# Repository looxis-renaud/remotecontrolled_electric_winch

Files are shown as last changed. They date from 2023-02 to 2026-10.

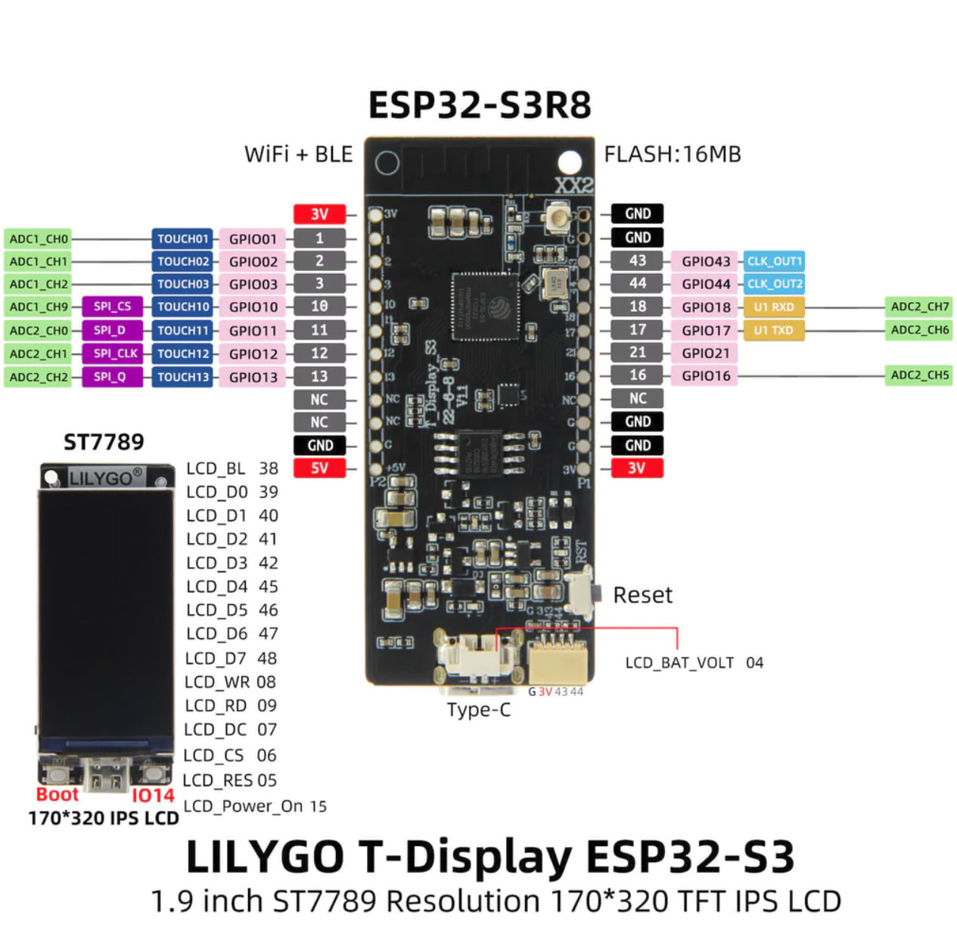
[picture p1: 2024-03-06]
doc/t-display-s3-pinout.jpg

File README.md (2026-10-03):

# Remote Controlled Electric Paraglider & Hangglider Winch

  - https://www.youtube.com/shorts/iNt1cCAZv0I (outdated video, will need to make a new one)

This is not a step by step guide of how to build your own electrical paraglider and hangglider winch, but it contains
most resources needed to build your own, including links to the most important components
- see doc/winch-schema.jpg for a simplified overview of all components needed
- doc/parts-list.md contains a list of the main parts and where to purchase them

This is not a finished project, rather a "work in progress". As of Sept. '26 I am currently improving some things, cleaning up,
changing the controller's case to a 3D-printed version, added a Daly BMS to the Battery. More on this later.

In the video above you can see the winch hanging on a steel post. Hauling it around
(getting into the trunk of my car, getting it out again, carrying) was extremely stressful,
since the winch is quite heavy, so I spent the winter of '23/'24 to move the winch onto a bike trailer.
The winch was able to rotate around it's Z-Axis, and fitted with the same arm to guide the line upwards
during the winch process. In Summer '24 this proved to not be ideal. A friend ( Bernd ) developed
a compact "Azimuth System", which is supposed to guide the line up and down and sideways during the winch-process.

During the winter 24/25 the rotary support and the arm were removed, a new frame and the azimuth system was built
and added to the system. I have done since then multiple step tows quite successfully and am really happy with the system.

As of today (July 25), I plan to keep this repo updated

# ewinch_remote_controller
 transmitter and receiver code for remote controlling a paragliding winch
 Based on LILYGO® TTGO ESP32-Paxcounter LoRa32 V2.1 1.6 Version 915MHZ LoRa ESP-32 OLED
 (http://www.lilygo.cn/prod_view.aspx?TypeId=50060&Id=1271&FId=t3:50060:3) 

Note: The 915MHz Version can transmit/receive in 868MHz and 915MHz, the desired frequency is defined in the code (transmitter.ino & receiver.ino)
  
Sketches: `transmitter/transmitter.ino` (handheld remote) and `receiver/receiver.ino` (winch, together with its helper
`LiPoCheck.cpp/.h`). Open the `.ino` in the Arduino IDE, compile and flash. The transmitter is the version flashed on my
remote (synced Sept '26: ID 3, `myMaxPull = 95`), except that the ESP-NOW monitor code is now commented out.

 receiver uses PPM (Pulse Position Modulation) for driving the winch and (optional) UART to read additional information (line length, battery %, dutycycle)
 VESC UART communication depends on https://github.com/SolidGeek/VescUart/ - Note: Line length seems to not be correctly transmitted, falls short by a factor of ~0,7
 
## To use Arduino IDE with the Lilygo TTGO ESP32 Paxcounter LoRa32
- In Arduino IDE open File > Preferences
- in additional boards manager URLS field copy: https://raw.githubusercontent.com/espressif/arduino-esp32/gh-pages/package_esp32_index.json
- click OK
- Go to Tools > Board > Boards Manager
- In Boards Manager Search for ESP32 and install **version 2.0.15** of “ESP32 by Espressif Systems“ (pick the version in the drop-down; 3.x is not tested with this code)
- Go To Tools > Board > ESP32 and select the TTGO LoRa32-OLED Board

## Install the Arduino libraries
Use the pinned library versions from [arduino-libs/](arduino-libs/README.md): copy the folders into your Arduino library folder (Windows: `Documents\Arduino\libraries\`). Don't update them casually, see the README there.
- [18650CL](https://github.com/pangodream/18650CL) 1.0.1
- [Button2](https://github.com/LennartHennigs/Button2) 2.3.2
- [VescUart](https://github.com/SolidGeek/VescUart) 1.0.1
- [OLED-SSD1306](https://github.com/ThingPulse/esp8266-oled-ssd1306) 4.5.0
- [LoRa](https://github.com/sandeepmistry/arduino-LoRa) 0.8.0

## PIN Setup Receiver:
IO 13 (PWM_PIN_OUT) // connect to PPM Port "Servo" on Vesc

IO 14 (VESC_RX)   //connect to COMM Port "TX" on Vesc

IO 2 (VESC_TX)   //connect to COMM Port "RX" on Vesc

IO 12 (Relay Signal) (for the VESC cooling fan) // connect red wire to 5V, black wire to GND and white cable (signal) to Pin 12. Wire the VESC cooling fan through the relay module. The receiver switches the fan automatically, see "Cooling fan" below. If your relay module is active-low, set `RELAY_ACTIVE_HIGH` to `false` in `receiver.ino`. Wire colours on this winch: see the table below.

### Receiver wiring harness (this winch)
Wire colours as they leave the TTGO LoRa board, recorded by Etienne on 2026-10-03. Two 6-pin plugs: the **female** plug goes only to the fan relay (doubled / free pins leave room for a later function), the **male** plug goes to the VESC. The main supply uses the small 2-pin connector that came with the board (on the transmitter the same connector goes to the 18650 cell).

| Plug | Board pin | Wire colour | Function |
|---|---|---|---|
| 6-pin **female** | IO15 | yellow | currently not used (the relay signal was wrongly on IO15 until 2026-10-02) |
| 6-pin **female** | IO12 | white | relay signal (cooling fan) |
| 6-pin **female** | GND | green & black | ground |
| 6-pin **female** | +5V | red & blue | 5 V supply |
| 6-pin **male** | IO2 | white | UART TX → VESC COMM RX (orange wire on the pre-made COMM plug) |
| 6-pin **male** | IO13 | yellow | PPM → VESC "Servo" port |
| 6-pin **male** | IO14 | blue | UART RX ← VESC COMM TX (green wire on the VESC side) |
| 6-pin **male** | + (main supply) | red | board supply from the VESC, via the small 2-pin battery connector on the TTGO board |
| 6-pin **male** | − (main supply) | black | board ground from the VESC, via the same 2-pin connector |

Colours of pre-made cables differ: go by the signal, not by the colour.

## PIN Setup Transmitter:
IO 15 (BUTTON_UP) //together with GND connect with push button for UP Command

IO 12 (BUTTON_DOWN ) //together with GND connect with a push button for STOP/BRAKE Command

A third button (IO 14) was used for the fan relay and the line cutter. It has no function any more.

## Cockpit monitor (retired)
I lost the cockpit monitor (LilyGO T-Display S3) in mid flight, and it added extra tech to take care of,
so I won't rebuild it. Its code and docs are archived in [old/](old/README.md). The matching ESP-NOW code in the
transmitter is commented out.

# VESC
VESC is the Open Source Electronic Speed Controler developed by Benjamin Vedder ( **V**edder **E**lectronic **S**peed **C**ontroller)
Topic has been moved here: [vesc/readme.md](vesc/readme.md). Hands-on guide for VESC Tool (faults, realtime data, settings, hall sensors): [vesc/vesc-tool-guide.md](vesc/vesc-tool-guide.md).

## Cooling fan
The VESC cooling fan is switched by a relay on receiver IO 12. The receiver decides by itself, there is no button for it:
- Fan **ON** as soon as a pull state (state 1 or higher) is active, including the failsafe default pull.
- Fan **OFF** 120 s after the last pull state (`FAN_RUN_ON_MS` in `receiver.ino`). The run-on lets the VESC cool down and keeps the fan from switching on and off during step tows.
- After power-up (soft brake) the fan stays off.
- After a release the remote usually stays in state 1 or 2 while AutoStop holds the drum, so the fan keeps running (the receiver does not know about the VESC AutoStop). It switches off 120 s after the remote goes to brake, or about 140 s after the remote is switched off (20 s failsafe defaultPull, then soft brake, then 120 s run-on).
- The receiver OLED shows "Fan ON", "Fan ON (off in … s)" during the run-on, or "Fan OFF".

The emergency line cutter was dropped (WINCH-05).

# Battery
16P10S Battery using 160 Lithium Ion 21700 cells with 4.000 mAh each.
 - 3,7V nominal per cell, max 4,2V, min 2,5V
 - ~60V total, max 67,2V, min 40V
 - 4Ah per cell = 40Ah total
 - 2,4 kWh

# usage:
Pull values below are for `myMaxPull = 95` in the transmitter (set it to roughly the pilot's take-off weight).
States 2-5 scale with it: prePull 18 %, takeOffPull 55 %, fullPull 80 %, strongPull 100 %.
defaultPull (7kg) and the brakes (-7kg / -20kg) are fixed values.

- A) prepare:
  1 - turn the VESC and receiver on
  2 - MAKE SURE to have the Potentiometer connected to ADC turned fully left (in my setup! need to measure whether this is open or closed :-) )
      If the Poti is rotated to the right, either partially or fully, the winch will not operate with the predefined Pull Torque!
  3 - pull the line out to the desired length (the VESC measures the line length that is being unwound, needed for the autostop to work).
      **Always pull the line out with the soft brake active (state -1, the start state), never in neutral (state 0).**

  > ⚠️ **WARNING - pull the line out with soft brake only!**
  > In neutral nothing holds the drum. When you walk faster and then stop, the drum keeps turning and unwinds
  > line right at the drum (overrun). On launch the loose turns cause a line wrap. **This has already happened
  > once:** the wrap destroyed the line and the (3D-printed) gear of the winch. The soft brake keeps the line
  > under light tension so the drum stops when you stop.
  > (The winding gears have since been replaced: first printed in plastic to check function and fit,
  > now laser-sintered steel for permanent use.)
  4 - go through your pre-flight preparations and clip in
- B) launch:
  1 - switch to defaultPull (7kg pull value) and prePull (to tighten the line (~17kg pull value) to assist you to launch the glider
  2 - go to takeOffPull (~52kg pull value) to assist you with launching the glider and gently getting into the air with a slight pull towards a safety margin of 15-30m height
  4 - click "Up" Button to increase Pull
- C) Step Towing:
  1 - switch to defaultPull (7kg pull value) before you turn away from winch to fly back to launch site
  2 - go to prePull (~17kg pull value) during turn towards next step (towards winch) to avoid line sag
  3 - after successful turn, go to fullPull again
 
- C) Release
  Go To defaultPull (7kg pull value) before you release. After releasing, rewind the line with LOW pull only:
  **maximum state 2 (prePull, ~17kg) - never higher.**
  The AutoStop feature (modified VESC Firmware is required, see vesc/vesc_ppm_auto_stop.patch) brakes the drum
  when approx. 15m of line are left - but only reliably at low rewind speed.

  > ⚠️ **WARNING - rewind with max. state 2 only!**
  > AutoStop only works reliably if the line is rewound with little pull (max. state 2 / prePull) after releasing.
  > With more pull, the brake is not strong enough to stop the drum in time: the carabiner is pulled into the
  > azimuth system and destroys it, or the line snaps. **This has already happened once** - the line broke and
  > tangled and the whole winch had to be rebuilt. (An earlier version of this README wrongly said to rewind
  > with fullPull.)

  > ⚠️ **WARNING - do NOT switch the remote off until the line is fully rewound and AutoStop has stopped the drum!**
  > The receiver does not know about the VESC AutoStop. If the remote goes off while the line is still being
  > rewound, the receiver failsafe keeps only defaultPull for 20 s and then switches to soft brake: the drum stops
  > and the rest of the line falls onto the towing track and stays there. **This has already happened once.**
  > Keep the remote on (state 1 or 2) until AutoStop has stopped the drum, and only then switch it off.
 
- D) Neutral
  You can get to neutral state only if you are in Brake Mode (-7kg), Double Press the ButtonDown to activate it.
  **Do not use neutral to pull the line out** (see the warning in A: the drum overruns and the line wraps).
  Use the soft brake instead. (An earlier version of this README recommended neutral for pulling the line out.)

- E) Rewinding the Cable
  If something does not go as expected (during one flight, I turned off the remote too soon after release: the failsafe stopped the winch, as designed, and the line fell on the ground, see the warning in C) Release):
  - use the Potentiometer, which should be on the far left position, to gently rotate it towards the right. The motor will start to rewind the line, regardless of the measured distance.

## Several pilots / several remotes
- **One pilot:** flash `transmitter/transmitter.ino` onto one remote with any ID from 1 to 15 (`myID`) and the pilot's take-off weight as `myMaxPull`. That's all you need to tow yourself.
- **Several pilots:** prepare one remote per pilot. For each remote, change `myID` (unique, 1-15) and `myMaxPull` (that pilot's take-off weight) in the code and flash it. Put a label with ID and max pull on each remote.
- **Who controls the winch:** the receiver follows only one remote at a time. The remote that is sending keeps control as long as it is switched on (it sends every 400 ms). Another remote can only take over after the active one has been **silent for 5 s** (switched off or out of range).
- **Admin remote (ID 0):** takes over immediately, at any time. When switched on, it listens for 4 s, starts in the state the winch is currently in, and from then on its buttons control the winch. Build it so it can't be confused with the others (Etienne's admin remote has a **red case**).
- ⚠️ When the admin remote is switched off again, the receiver keeps the last state; if it was a pull state, it goes to failsafe after 1.5 s (default pull, soft brake after 20 s). After 5 s **any other remote that is still switched on takes over with whatever state it is sending**. Before switching the admin remote off, make sure the other remotes are off or in a safe state (soft brake).
- All remotes and the receiver must run the same code version (same LoRa message format), see [features/INDEX.md](features/INDEX.md).

# Roadmap / ToDo
Planned changes, open bugs and ideas are tracked in [features/INDEX.md](features/INDEX.md), one file per feature.

# Notes
from Robert's "Issue Section"
- calibrate PWM Settings for pull Values: Depending on your motor (power, KV value, diameter, etc.) you need to scale the resulting kg pull on your line.
I think the best way is to adapt the "Motor Current Max" and "Motor Current Max Brake" value in the Vesc Motor Settings (General -> Current).
You could also adapt the "Pulselength Start" and "Pulselength End" in the Vesc App settings (PPM -> Mapping) to reach the same goal.
I used a suitcase scale to measure the real pull on the line.
With my QS260 hub motor I have around ~3,6A/kg pull.
- Motor amount of Poles: 32

# Big "Thank You"

A big "Thank You" goes to Robert Zach, from whom I copied this project (and forked his code).
https://github.com/robertzach/ewinch_remote_controller
Many Thanks to Bernd Otterpohl for designing the Azimuth System and making the files available
Many Thanks to Nico Stucke and Hans Werner Stucke for making the frame and the actual azimuth system.

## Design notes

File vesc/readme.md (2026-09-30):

# VESC Introduction
VESC is the Open Source Electronic Speed Controler developed by Benjamin Vedder ( **V**edder **E**lectronic **S**peed **C**ontroller).

# The controller used on this winch: Trampa VESC 75/300

The winch runs on a **Trampa VESC 75/300** (hardware revision `75_300_R3`), driving the QS Motor 12kW 260 V4 hub motor in FOC mode.
It is flashed with the patched autostop firmware [vesc_75_300_auto_stop.bin](vesc_75_300_auto_stop.bin) (see "Line auto stop in VESC" below).

Manufacturer manual (PDF): [VESC-75-300-MKIV-MANUAL.pdf](VESC-75-300-MKIV-MANUAL.pdf)

Product page: https://trampaboards.com/vesc-75v-300a-black-anodised-non-conductive-cnc-housing--the-most-powerful-vedder-electronic-speed-controller-ever-p-26284.html

## What matters for the winch

| Topic | Controller spec | What it means for this winch |
|---|---|---|
| Voltage | 12V – 67.2V (4S–16S LiPo/Li-ion), spikes must never exceed **75V** | Our 16S battery is at exactly **67.2V** when fully charged, which is the upper limit. Braking (brake states, autostop) is regenerative and feeds energy back into the battery, raising the voltage. Braking hard with a freshly, fully charged battery is therefore the most critical case for overvoltage. Never charge above 4.2V/cell. |
| Current | 300A continuous, 400A burst, **depending on mounting, ambient temperature and air circulation** | The continuous rating assumes good cooling. That is why the VESC has a cooling fan (see main README), and why the enclosure needs airflow around the heat sink. |
| Regenerative braking | Energy is recovered during braking | Brake states (-1 soft / -2 hard) and autostop brake with motor current; see voltage note above. |
| Protection | Under/over voltage, over current, over temperature (motor and ESC) | If a limit is hit, the VESC reduces or cuts motor power, including **during a tow**. Keep the battery charged and the controller cool. |
| Real-time data | Motor temperature, current, voltage | The receiver reads battery voltage, motor temperature, tachometer and duty cycle via UART and shows them on the remote. |
| Aux power outputs | 12V 1A (switchable), 5V 1A, 3.3V 0.5A; **all combined max. 1A** | Everything powered from these outputs (e.g. cooling fan, relay, potentiometer, receiver, the winch camera from WINCH-19, depending on the build) shares this 1A budget. |

## From the manual: wiring & safety notes

Winch-relevant points from the manufacturer manual ([PDF](VESC-75-300-MKIV-MANUAL.pdf)). The PDF is the authoritative source; this is only a summary.

> **Note:** The manual describes a **newer revision (MKVI)** than the controller on this winch. Connector types and positions differ: the winch's controller has **Mini-USB** instead of USB-C, and its power-switch connector sits in a different place. The general wiring and safety rules still apply, but check port positions and pinouts on the actual device, not in the manual's drawings.

**Manufacturer warning.** Trampa states the VESC "may not be used for applications requiring fulfillment of special safety standards", explicitly naming aircraft and safety-critical environments. A tow winch is exactly such an application. The winch uses the controller anyway, so the other safety layers (VESC autostop, receiver failsafe, the rewind rule in the main README) must never be weakened or skipped.

**Minimum power path (battery → VESC):**
- Safety power cut-off.
- Fuse rated for the weakest part of the electrical system.
- Anti-spark / pre-charge: anti-spark connectors (e.g. XT90S) and/or an anti-spark switch. **Never power the VESC without pre-charge**; the capacitors must charge slowly, otherwise permanent damage may result.
- A BMS is required when the motor is used for regenerative braking. On the winch this is always the case (brake states and autostop).
- All 3 battery input cables and all 3 motor phase wires must be connected and properly insulated; wire gauge must match the current.
- Keep the controller dry; the enclosure must protect it against water.

**Connectors** (as described for the MKVI: signal ports JST-PH, 2 mm pitch. On the winch's older controller USB is Mini-USB and connector positions differ):

| Port | Manual | On this winch |
|---|---|---|
| PPM | Input from an RC receiver. Never connect one receiver to several VESCs (Y-PPM); use opto decouplers. | PPM signal from the LoRa receiver (IO13). |
| COMM | UART, I²C and ADC; on the MKVI also the power-switch pin. | UART telemetry to the receiver; potentiometer on ADC2 (see "Line auto stop in VESC"). |
| Sensors | Hall, ABI or AS5047P motor position sensors (3.3 V or 5 V). | Motor sensor cable (3 hall sensors + KTY83-122 temperature sensor) connected, FOC hall mode active since 2026-09-30. Wire colours: [doc/qs-motor/README.md](../doc/qs-motor/README.md). |
| Motor A/B/C | Phase colours: A = yellow, B = blue, C = red (for correct display in VESC Tool). | QS Motor phases. |
| CAN | Only connect CAN H and CAN L; all devices on the same battery GND. | Not used. |
| USB | Configuration, firmware update, real-time data (USB-C on the MKVI). | VESC Tool via **Mini-USB**. |
| AUX | 12 V out (SIG, software-switched). | Counts towards the 1 A aux budget above. |

**LED codes** (useful for troubleshooting):

| LED | Meaning |
|-----|---|
| Blue | Powered up |
| Green, dim | Firmware running |
| Green, bright | Driving the motor |
| **Red** | **Fault.** Connect VESC Tool and read out the fault code before the next tow. |

**Power switch.** For the MKVI, the manual describes a momentary **normally closed (NC)** switch on the COMM power-switch pin, with three wiring options (illuminated NC switch, plain NC switch, or a separate soft-start switch without auto power-off). This does not apply 1:1 to the winch's older controller, whose power-switch connector is in a different place.

**On this winch:** an on/off switch on the controller's power-switch connector. **Switch open = VESC off, switch closed = VESC on.**

*Source: Trampa VESC 75/300 manual, pages 1, 3 and 4.*

## Technical specifications (manufacturer data)

**Voltage**
- 12V – 67.2V (safe for 4S to 16S LiPo/Li-ion). Voltage spikes may not exceed 75V
- 12V 1A switchable output for external electronics
- 5V 1A output for external electronics
- 3.3V 0.5A output for external electronics
- Combined 3.3V, 5V, 12V: no more than 1A

**Current**
- Continuous 300A, burst 400A (values depend on the mounting, ambient temperature and air/water circulation around the device)

**Motor control modes**
- DC, BLDC, FOC (sinusoidal). This winch uses **FOC**.
- Sensored, sensorless or hybrid operation
- Sensorless modes: HFI, VSS, 45 Deg V0V7 HFI (Silent), 45 Deg V0 HFI, Coupled V0V7 HFI (Silent), Coupled V0 HFI
- High ERPM drivable: 100–150K (motor/system dependent)

**Supported sensors**
- Hall sensors
- Encoders: ABI, AS5047, AS5X47U, SIN/COS, TS5700N8501 (incl. multiturn), MT6816, BISSC, TLE5102, custom encoder

**Communication**
- USB, SWD
- PWM in/out (this winch: PPM input from the receiver on the "Servo" port)
- UART x2 (this winch: telemetry to the receiver on the COMM port)
- SPI and I²C
- CAN, UAVCAN and custom CAN commands
- Wireless connectivity via accessory (WiFi/BLE)
- 2x programmable GPIO pins

**Other technical features**
- Current and voltage measurement on all phases (3 phase shunts), adjustable current and voltage filters (full phase filters)
- 3 individual gate drivers
- Accelerometer and gyro (9 axis, ±2/±4/±8/±16 g full scale)
- Hibernation with wake-up via power switch options (momentary NC), automatic hibernation with adjustable timer, 20µA consumption while hibernating (less than battery self-discharge)

**Software**
- VESC Tool: https://vesc-project.com/vesc_tool (desktop), mobile apps for Android/iOS
- Motor and input setup wizards
- Scripting support (QML and LISP)

**Housing**
- Precision CNC aluminium heat sink housing, black hard anodised
- Mounting holes for easy attachment
- Outer dimensions: 141 x 82 x 18 mm

*Source: Trampa product page (manufacturer data), retrieved September 2026.*

# VESC setup (VESC Tool)

The VESC is configured with **VESC Tool** (https://vesc-project.com/vesc_tool) over USB. This section explains the setup steps and the background needed to understand them.

**Hands-on guide** (connecting, read/write, backups, terminal and faults, realtime data, ERPM and hall ranges, temperature sensor, hall detection): [vesc-tool-guide.md](vesc-tool-guide.md).

> ⚠ **Firmware:** The VESC runs **FW 5.3** with the autostop patch (read out in VESC Tool on 2026-09-30, HW `75_300_R3`). Use the matching **VESC Tool 3.01**. A newer VESC Tool may offer a **firmware update: decline it.** An update would replace the patched autostop firmware ([vesc_75_300_auto_stop.bin](vesc_75_300_auto_stop.bin)) with a stock firmware without line autostop.
>
> **Backups:** Before and after every change, save the motor and app configuration as XML files in VESC Tool and commit them to this folder with a date prefix, e.g. `260929_motor_config.xml`.

## Background: BLDC vs. FOC

The QS hub motor has a rotating outer ring with permanent magnets and fixed copper coils inside. The VESC sends current through the coils. The resulting magnetic field pulls on the magnets and turns the ring. To do this right, the VESC must know at every moment **where the magnets are** (the rotor position), so it can energise the right coil at the right time. With wrong timing the motor pulls weaker, stutters or twitches backwards.

BLDC and FOC are two ways of driving the coils:

| | BLDC (block commutation) | FOC (Field Oriented Control) |
|---|---|---|
| How | Switches the coils hard on and off in 6 fixed steps per electrical revolution | Controls the current in all three coils continuously as smooth sine waves, so the field always pulls at the optimal angle |
| Picture | Pushing a swing with single hard shoves | Guiding the swing smoothly all the way |
| Result | Simple and robust, but louder, slightly pulsing torque, less efficient | Quiet, smooth, efficient, **precise torque control** |

**The winch uses FOC** (`motor_type = 2` in all configs in this folder), and that is the right choice: the pull on the line is proportional to the motor current (torque = current × motor constant). The pull states from the transmitter end up as current commands, and FOC turns them into a smooth, non-pulsing pull.

## Background: sensorless vs. hall sensors

BLDC or FOC is about *how* the coils are driven. A separate question is *how the VESC knows the rotor position*.

**Sensorless:** A turning motor induces a voltage in its coils (back-EMF). The VESC measures it and calculates the rotor position from it (the "observer"). The problem: this voltage is proportional to speed. At standstill it is zero, at very low speed it is tiny, so the VESC cannot "see" the rotor well. When starting it has to guess. Without load this usually works; **under load it can stutter, jerk or briefly turn the wrong way.** HFI (high frequency injection) is a workaround that finds the position with an audible test signal and needs careful tuning.

**Hall sensors:** Three small magnetic field sensors inside the motor report a coarse rotor position (6 sectors per electrical revolution) over the sensor cable, **also at standstill.** In FOC hall mode the VESC uses the hall signals below `foc_sl_erpm` and switches to the more precise sensorless observer above it.

What this means on the winch (rough numbers from the config: 32 magnets = 16 pole pairs, drum diameter 0.43 m):

- `foc_sl_erpm = 2000` ERPM ÷ 16 ≈ **125 rpm of the drum ≈ 2.8 m/s (≈ 10 km/h) line speed.** Below that, hall mode uses the sensors.
- That is exactly where a winch works a lot, **at standstill or slowly, under high load:** pre-tensioning with the pilot still standing, the transition from brake to pull, braking to standstill (autostop, end of rewind), and the start of the rewind.
- With hall sensors these phases are smooth and predictable. Sensorless they can be jerky, depending on motor and tuning.

Things to know:

- **The 6-wire sensor cable also carries the motor temperature sensor** (5 V, GND, H1, H2, H3, TEMP). The motor has a **KTY83-122** sensor, so `m_motor_temp_sens_type` must be **KTY83/122** (Motor Settings → General → Advanced → Motor Temperature Sensor Type). With this setting an unplugged cable reads as extremely hot: the VESC raises `FAULT_CODE_OVER_TEMP_MOTOR` and gives no current. **The sensor cable must always be connected.**
- ⚠ **Wrong sensor type = no current.** Until 2026-09-30 the type was set to NTC 10k. The KTY83's ~1 kΩ then reads as ~100 °C, above the 75/85 °C motor limits: red LED, `FAULT_CODE_OVER_TEMP_MOTOR`, the motor doesn't turn (not even with the potentiometer). That was the "VESC error with the sensor cable connected" from WINCH-16.
- **Downside of hall mode:** the VESC depends on the sensor cable. A loose plug, broken wire or faulty sensor gives wrong positions: jerks, weak pull or fault codes. Cable and connectors must be reliable. Sensorless mode has no such dependency.
- **Plugging in the cable alone changes nothing.** The VESC only uses the sensors when the sensor mode is set to *Hall* **and** the hall table has been measured (see below).

**Current state (2026-09-30): the winch runs in FOC hall mode** (`foc_sensor_mode = 2`, backup [260930_motor_config.xml](260930_motor_config.xml)). Hall table measured: `255, 65, 118, 103, 199, 34, 173, 255`. Until then it ran sensorless (June 2024 config, now in [old/vesc-configs/](../old/vesc-configs/)). Check in VESC Tool: **Motor Settings → FOC → General → Sensor Mode.**

Note: **Motor Settings → General → "Sensor Port Mode: Hall Sensors"** only says what kind of sensor could be connected to the port (hall, ABI encoder, AS5047). It does not switch hall mode on; that is the FOC Sensor Mode.

## Hall sensors: how they were set up (and how to redo it)

> ⚠ **Safety-relevant.** Hall mode changes how the motor starts and brakes. Bench test first, then field test. Tracked in [WINCH-17](../features/WINCH-17-hall-sensors-foc.md).

Chosen because the winch spends its most critical moments (start, pre-pull, braking, autostop) at low speed under load, and because the sensor cable also provides the motor temperature protection.

**Prerequisites**
1. Sensor cable checked wire by wire (5 V, GND, H1, H2, H3, TEMP). Test procedure for the temperature sensor and the three hall sensors (German): [doc/qs-motor/sensors-troubleshooting.md](../doc/qs-motor/sensors-troubleshooting.md). Wire colours: [doc/qs-motor/README.md](../doc/qs-motor/README.md) (plug colours differ from motor wire colours). Status 2026-09-30: hall sensors of sensor set 1 intact, temperature sensor 0.97 kΩ at ~25 °C (KTY83-122).
2. Motor temperature sensor type set to **KTY83/122** (see above), otherwise `FAULT_CODE_OVER_TEMP_MOTOR`.

**Procedure** (done this way on 2026-09-30; **not** with the Setup Motor FOC wizard, which would also reset current limits, battery and temperature settings)
1. Save the current motor and app configuration as XML (backup).
2. Potentiometer at the "off" end. Secure the winch. **Unhook the line or make sure there is no load on it, and keep everyone away from the drum: the motor turns by itself during detection.**
3. Motor Settings → FOC → **Hall Sensors** tab: run only the hall detection (default detection current; increase in small steps if the motor doesn't turn).
4. Check the hall table: entries 1–6 must have values, only entries 0 and 7 are 255. If more entries are 255, a sensor or wire is faulty. Do not use hall mode then.
5. Apply the table, set FOC → General → **Sensor Mode = Hall** (Sensorless ERPM stays 2000), **write** the motor configuration.
6. Short test with the potentiometer (little travel): smooth start from standstill and smooth braking from slow speed. Then `faults` in the VESC Tool terminal.
7. Read the configuration back, save it as XML and commit it to this folder.

**Bench checks** (workshop, no pilot)
- Smooth start from standstill in the pull states, also against load (line held / tied back), no jerks or backwards twitch.
- Brake to standstill (soft brake, hard brake) without jerks.
- Motor temperature on the remote is plausible (about ambient temperature when cold).
- Line length counts up and down ([WINCH-16](../features/WINCH-16-uart-telemetry-zero.md)).
- Unplug the sensor cable deliberately once on the bench (low pull state only) to see how the VESC reacts, so the failure mode is known. Expected with the KTY83/122 setting: `FAULT_CODE_OVER_TEMP_MOTOR` (open temperature input reads as very hot), no current.

## Setup wizards

VESC Tool has two wizards on the welcome page: **Setup Motor FOC** and **Setup Input**.

### Setup Motor FOC

The wizard asks roughly for:
- the motor class (e.g. large hub motor),
- the battery (type, number of cells: 16, capacity, current limits),
- drive setup (wheel/drum diameter, motor poles: 32, gear ratio 1),

and then **measures the motor**. The motor makes noises and **turns during the measurement** (no line load, nobody at the drum). Afterwards it lets you choose the motor direction.

What it measures and calculates (values from [260930_motor_config.xml](260930_motor_config.xml); R, L and λ were measured in 2024 and are unchanged):

| Value | Config name | Value in backup | What it means in simple words |
|---|---|---|---|
| Resistance R | `foc_motor_r` | 4.34 mΩ | Electrical resistance of the copper windings. Determines the heat losses (heat = I² × R: at 200 A about 170 W in the windings) and is needed for current control. |
| Inductance L | `foc_motor_l` | 17.8 µH | How "sluggish" the windings are against changes in current. Determines how fast the VESC can change the current. |
| Flux linkage λ | `foc_motor_flux_linkage` | 26.1 mWb | Strength of the magnets as seen by the coils. The key motor constant: it links **current to torque** and **speed to voltage**. |
| Current controller gains | `foc_current_kp`, `foc_current_ki` | 0.0178 / 4.34 | Settings of the VESC's internal current regulator. Not measured but **calculated from L and R** (here L × 1000 and R × 1000). |
| Observer gain | `foc_observer_gain` | 1.47 × 10⁶ | Tuning of the sensorless position estimator (used above `foc_sl_erpm`), **calculated from λ**. |
| Hall table | `foc_hall_table__0…7` | 255, 65, 118, 103, 199, 34, 173, 255 | Which rotor angle each of the 6 hall sensor combinations stands for. Measured by the hall detection on 2026-09-30. |

Rough cross-check with λ (theoretical, ignoring friction and losses): torque per amp ≈ 1.5 × 16 pole pairs × 0.0261 ≈ 0.63 Nm/A. At a drum radius of 0.215 m that is ≈ 2.9 N per amp, i.e. **≈ 3.4 A per kg of line pull.** This fits the ≈ 3.6 A/kg estimate used for the pull states (see [WINCH-14](../features/WINCH-14-pull-value-calibration.md)). The effective drum radius grows as line is wound on, so the real value varies.

After the wizard, **compare the motor settings with the last backup.** The wizard sets current limits and other values based on the chosen motor class and battery, and these can differ from the values the winch was set up with (table below).

### Setup Input

Configures how the VESC reads the PPM signal from the LoRa receiver. The receiver outputs pulses between 950 µs (hard brake side) and 2000 µs (full pull side). In VESC Tool these are the pulse start / center / end values:

| Config | Pulse start | Center | End |
|---|---|---|---|
| [260930_app_config.xml](260930_app_config.xml) (this winch, unchanged since June 2024) | 0.933 ms | 1.458 ms | 1.984 ms |
| [old/vesc-configs/vesc_app_config.xml](../old/vesc-configs/vesc_app_config.xml) (Robert, for comparison) | 1.1 ms | 1.459 ms | 1.768 ms |

> ⚠ **Do not re-run the input wizard casually.** The pulse range defines how many amps each pull state means, i.e. the actual pull in kg. Changing it is safety-relevant, needs Etienne's decision and a bench test, and should go together with the pull calibration ([WINCH-14](../features/WINCH-14-pull-value-calibration.md)).

## Motor Settings

Motor settings are specific to the motor. **Every time a different motor is connected, the motor must be set up again** (Setup Motor FOC), otherwise the VESC and/or the motor can be damaged. Changes only take effect after the motor configuration has been **written** to the VESC.

Settings worth knowing (values from [260930_motor_config.xml](260930_motor_config.xml), read from the VESC on 2026-09-30):

| Setting | Config name | Value in backup | Note |
|---|---|---|---|
| Motor current max / min | `l_current_max` / `l_current_min` | 250 A / −250 A | Upper limit for pull and brake torque. |
| Battery current max / min | `l_in_current_max` / `l_in_current_min` | 290 A / −290 A | Max. current drawn from / fed back into the battery. Must fit the BMS. |
| Absolute max current | `l_abs_current_max` | 290 A | Hard cut-off: above this the VESC faults. |
| Battery cutoff start / end | `l_battery_cut_start` / `l_battery_cut_end` | 54.4 V / 48 V (3.4 / 3.0 V per cell) | Below "start" the VESC reduces the current, at "end" it stops. The battery voltage sags under load, so with a partly discharged battery the **pull can be reduced during a tow**. |
| Max input voltage | `l_max_vin` | 72 V | Over-voltage fault. Full battery = 67.2 V; regenerative braking raises it. ⚠ Triggered on 2026-09-30 when braking from full speed, see [WINCH-22](../features/WINCH-22-overvoltage-regen-braking.md). |
| Motor temp start / end | `l_temp_motor_start` / `l_temp_motor_end` | 75 °C / 85 °C | Current is reduced between these. **Only works with the temperature sensor connected and the right sensor type.** |
| FET temp start / end | `l_temp_fet_start` / `l_temp_fet_end` | 85 °C / 100 °C | Controller temperature; see cooling fan. |
| Motor type | `motor_type` | 2 = FOC | |
| Sensor mode | `foc_sensor_mode` | 2 = Hall | Since 2026-09-30 (was 0 = sensorless). |
| Sensorless switch-over speed | `foc_sl_erpm` | 2000 ERPM | Below this, hall mode uses the sensors; above it the sensorless observer. |
| Hall interpolation | `foc_hall_interp_erpm` | 500 ERPM | Above this, the VESC interpolates between hall sectors. |
| Motor temp sensor type | `m_motor_temp_sens_type` | 2 = KTY83/122 | Matches the motor (KTY83-122). Was 0 = NTC 10k until 2026-09-30, which caused `FAULT_CODE_OVER_TEMP_MOTOR`. |
| Auxiliary output mode | `m_out_aux_mode` | 11 = "Temp motor or mosfet > 50 C" | AUX output switches on above 50 °C. What is connected to which 12 V output: see [WINCH-07](../features/WINCH-07-automatic-cooling-fan.md). |
| Motor poles | `si_motor_poles` | 32 | 16 pole pairs. |
| Wheel (drum) diameter | `si_wheel_diameter` | 0.43 m | Used for speed/distance in VESC Tool. |
| Battery cells / capacity | `si_battery_cells` / `si_battery_ah` | 16 / 40 Ah | 16S10P × 4 Ah. |

## App Settings

App settings define which input the VESC listens to. Changes only take effect after the app configuration has been **written** to the VESC.

| Setting | Config name | Value in backup | Note |
|---|---|---|---|
| App to use | `app_to_use` | 4 = PPM and UART | PPM = pull command from the receiver, UART = telemetry to the receiver. |
| UART baud rate | `app_uart_baudrate` | 115200 | Must match `receiver.ino`. |
| PPM control type | `app_ppm_conf.ctrl_type` | 3 | "Current, no reverse, with brake" (FW 5.x numbering; confirm in VESC Tool). |
| PPM ramp up / down | `app_ppm_conf.ramp_time_pos` / `_neg` | 1 s / 0.5 s | VESC-side smoothing, on top of the receiver's own smoothing. |
| Timeout | `timeout_msec` / `timeout_brake_current` | 1000 ms / 10 A | If the PPM signal is missing for 1 s, the VESC brakes with 10 A. |

The potentiometer on ADC2 is handled by the autostop firmware patch, not by a normal app (see "Line auto stop in VESC" below).

**Toolbar:** On the right-hand side of VESC Tool there are buttons for motor (**M**) and app (**A**) configuration: *read* the configuration from the VESC, *read default* configuration, and *write* the configuration to the VESC. Always read first, change, then write. Go by the tooltips: in VESC Tool 3.01 **write** is the icon with the arrow pointing **down**.

## Config backups in this repo

| File | Origin | Content |
|---|---|---|
| [260930_motor_config.xml](260930_motor_config.xml) | Etienne, 2026-09-30 | **Current** motor config of this winch: FOC hall mode, KTY83/122 temperature sensor |
| [260930_app_config.xml](260930_app_config.xml) | Etienne, 2026-09-30 | **Current** app config of this winch (PPM + UART; unchanged since June 2024) |

Older backups (June 2024 sensorless config, Robert Zach's 2022 configs) are archived in [old/vesc-configs/](../old/vesc-configs/). Keep only the current backups here; move superseded ones to `old/vesc-configs/`.

**PLEASE NOTE:** Don't just load a motor config and write it to your VESC. Use it as an example only. Always run the **Setup Motor FOC** wizard so the VESC measures the real motor (resistance, inductance, flux linkage, hall sensors).

## Line auto stop in VESC
Line auto stop can be implemented within VESC with vesc_ppm_auto_stop.patch

For this to work properly, either connect a Potentiometer to ADC2 and GND to manually control the winch. E.g. To wind up the last meters of the line when finishing. Or to manually set a tension when used as a rewind winch. Note that the potentiometer only reduces tension/speed of the motor when it is running one of the pull programs as controlled via the transmitter!

> ⚠ **IMPORTANT: If you do not install a potentiometer, connect ADC2 to GND.** An open (floating) ADC2 input can read above 0.5 V. The VESC then switches to manual mode and ignores the remote: **the winch starts to pull on its own.** The same applies to a broken wire at the potentiometer (see failure modes below).

### Potentiometer: wiring

The potentiometer sits on the **COMM** port of the VESC (JST-PH connector). It divides the VESC's supply voltage and feeds the result to ADC2. The firmware patch compares the ADC2 voltage against the 3.3 V reference: **below 0.5 V = normal PPM operation (remote in control), above 0.5 V = manual mode** (current proportional to the potentiometer position, PPM input ignored).

Wiring on this winch (Etienne, 2026-09-30), potentiometer **viewed from below**:

| Potentiometer pin | VESC COMM signal | Wire colour (JST cable on this winch) |
|---|---|---|
| left | GND | yellow |
| middle (wiper) | ADC2 | orange |
| right | VCC | red |

- The wire colours are those of the JST cables used on this winch. Pre-made JST cables come in different colours: go by the signal on the COMM port, not by colour.
- **VCC must be 3.3 V, not 5 V.** The ADC measures up to 3.3 V. Check the voltage on the VCC wire with a multimeter before connecting the potentiometer. *To be completed:* confirmed voltage and pin position on the COMM port of this controller (the Trampa manual shows a newer revision).
- **Direction:** swapping the two outer pins reverses the direction. The "off" end is the end where ADC2 reads **0 V**. According to Etienne's notes that is **fully left (counter-clockwise)**. *To be verified* (WINCH-08).

**Check after wiring (winch secured, line without load):**

1. Turn the potentiometer to the "off" end. VESC Tool → Realtime Data (or multimeter between ADC2 and GND): ADC2 must read about **0 V** (well below 0.5 V).
2. Turn it slowly to the other end: the voltage must rise smoothly up to about 3.3 V. Above 0.5 V the motor starts to pull in manual mode.
3. Back to the "off" end: the winch must follow the remote again.

### Potentiometer: which part

| Property | Recommendation | Why |
|---|---|-----|
| Resistance | **10 kΩ** (5–10 kΩ is fine) | Only ~0.3 mA from the 3.3 V supply (the aux outputs share a 1 A budget). Much higher values make the ADC reading noisy. |
| Taper | **linear** (marked "B", e.g. "B10K") | Pull increases evenly with the rotation angle. A logarithmic ("A") taper makes the range near the off end very insensitive and then very steep. |
| Type | single-turn rotary potentiometer, 3 pins, panel mount (thread + nut), 6 mm shaft | Can be mounted securely in the enclosure wall. |
| Robustness | sealed / dust- and splash-proof if possible, solid metal housing | The winch is used outdoors. A dirty track can make the wiper jump. |
| Knob | knob with a clear pointer, "OFF" end marked on the enclosure | The "off" position must be recognisable at a glance before every tow (pre-flight check). |

### Potentiometer: failure modes

| Fault | ADC2 reads | Effect |
|---|---|---|
| ADC2 not connected / wiper wire broken | undefined (floating) | may switch to manual mode at random: **winch pulls on its own** |
| GND wire to the potentiometer broken | ~3.3 V | **full manual current**, remote ignored |
| VCC wire broken | ~0 V | manual mode no longer possible, remote works normally |
| Potentiometer not at the "off" end | > 0.5 V | manual mode, remote ignored |

Connectors and wires to the potentiometer therefore need strain relief and must be checked regularly.

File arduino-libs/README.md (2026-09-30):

# Arduino libraries (pinned versions)

Copies of the exact library versions used to build `transmitter/` and `receiver/`. They are kept in the repo so the winch firmware can always be rebuilt with the same code, even if a library changes or disappears upstream. See [WINCH-20](../features/WINCH-20-pin-toolchain-libraries.md).

**Do not update these libraries casually.** Update one library at a time, as its own feature, with a bench test (for example, a new Button2 version could change click, double-click or long-press timing, which drives the pull state machine).

## Versions

| Library | Version | Used by | Source | License |
|---|---|---|---|---|
| [Button2](Button2/) | 2.3.2 | transmitter | https://github.com/LennartHennigs/Button2 | MIT |
| [LoRa](LoRa/) | 0.8.0 | transmitter, receiver | https://github.com/sandeepmistry/arduino-LoRa | MIT |
| [VescUart](VescUart/) | 1.0.1 | receiver | https://github.com/SolidGeek/VescUart | GPL-3.0 |
| [ESP8266 and ESP32 OLED driver for SSD1306 displays](ESP8266_and_ESP32_OLED_driver_for_SSD1306_displays/) | 4.5.0 | transmitter, receiver | https://github.com/ThingPulse/esp8266-oled-ssd1306 | MIT |
| [Pangodream_18650_CL](Pangodream_18650_CL/) | 1.0.1 | transmitter, receiver | https://github.com/pangodream/18650CL | MIT |

Each folder is an unmodified copy of the installed library, including its license file. Taken from Etienne's Arduino library folder (installed February to April 2024) on 2026-09-30.

The rest of the toolchain can't be stored here and is pinned by version:

| Part | Version |
|---|---|
| Arduino IDE | 2.3.2 (the old IDE 1.8.x was removed on 2026-09-30; don't use it) |
| Board package "esp32 by Espressif Systems" | **2.0.15** (install exactly this version in the Boards Manager; 3.x has breaking changes) |
| Board | TTGO LoRa32-OLED (`esp32:esp32:ttgo-lora32`) |

## Status

- 2026-09-30: both sketches (state of WINCH-05/06/07) **compile** against exactly these copies (arduino-cli 0.35.3 from Arduino IDE 2.3.2, esp32 core 2.0.15).
- Bench and field tests with firmware built from these versions: *to be completed* after the WINCH-05/06/07 flash. The firmware on the winch before that was possibly built on another machine with unknown library versions (see WINCH-02).

## How to use them

**Arduino IDE:** copy the five library folders from `arduino-libs/` into your Arduino library folder (Windows: `Documents\Arduino\libraries\`), replacing other versions of the same libraries. Then open the sketch, select the board and compile as usual. In the IDE, *Tools → Manage Libraries* should show the versions from the table above.

**arduino-cli** (used by Claude for compile checks, no need to copy anything):

```
arduino-cli compile --fqbn esp32:esp32:ttgo-lora32 --libraries arduino-libs transmitter
arduino-cli compile --fqbn esp32:esp32:ttgo-lora32 --libraries arduino-libs receiver
```

ESP32Servo is no longer needed (line cutter removed in WINCH-05).

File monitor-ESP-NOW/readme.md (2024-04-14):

## Nearby Monitor with ESP-NOW Communication Protocol ##
 Using a Lilygo ESP32 T-Display S3 board ( https://www.lilygo.cc/products/t-display-s3 ) 
 to communicate with the Lilygo ESP32 LoRa board over ESP-NOW Protocol to
 - display winch-data and current Pull Value in Pilot's sight (on cockpit)
 - use buttons to control Fan, Warning light and Emergency Line Cutter via the transmitter
 - use a rotary encoder to be able to change the maxPull Value on the transmitter

## based on ##
 - https://github.com/VolosR/t-displayESPNOW/tree/main/Examples
 - https://www.youtube.com/watch?v=wKs2BjljM3E
 - https://randomnerdtutorials.com/esp-now-esp32-arduino-ide/
 - https://www.youtube.com/watch?v=3TswcJifxxI
 - https://github.com/VolosR/PbarrTut

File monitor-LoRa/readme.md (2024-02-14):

## Additional Lilygo TTGO ESP32 Paxcounter LoRa32 as a Monitor
 The "monitor" (monitor.ino) is basically an additional Lilygo LoRa ESP 32 that just listens
 to LoRa communication between transmitter and receiver and displays
 data on the oled display. I am "playing around" to add an external round oled or squared TFT Display
 for displaying the data nicely on a bigger screen (bigger than the original oled of the ESP32 Lora board)

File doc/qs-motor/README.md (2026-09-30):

# QS Motor 12kW 260 V4 (hub motor)

The winch drum is driven directly by a QS Motor 12kW 260 V4 hub motor. The motor housing (outer rotor) turns with the drum; the axle is fixed. The motor is driven by the Trampa VESC 75/300 in FOC mode, see [vesc/readme.md](../../vesc/readme.md).

This page collects what is known about the motor. Values marked *to be completed* are still missing. Please fill them in when known and name the source.

## Files in this folder

| File | Content |
|---|---|
| [QSMOTOR-Motor-Manual-V1.57.pdf](QSMOTOR-Motor-Manual-V1.57.pdf) | QS general motor manual: wire colours, pole pairs, hall and temperature sensor checks, temperature limits, waterproofing, mounting, hall replacement |
| [QSMOTOR-Connection-Manual-Kelly.pdf](QSMOTOR-Connection-Manual-Kelly.pdf) | QS connection manual for car hub motors with Kelly controllers: phase and hall wiring, spare hall set |
| [sensors-troubleshooting.md](sensors-troubleshooting.md) | Test procedure for the temperature sensor and the three hall sensors (German) |

## Identification

- **Model:** QS Motor 12kW 260 V4 hub motor, ordered as version "72V 100kph" ([AliExpress listing](https://www.aliexpress.com/item/4001237537247.html), see [parts list](../parts-list.md)).
- According to the QS manual, V3/V4 motors are marked "WP" on the motor.
- Serial number, purchase date, exact order specification: *to be completed*.

## Known data

| Item | Value | Source |
|---|---|---|
| Rated power | 12 kW | Product name |
| Pole pairs | **16** (32 magnets) | QS manual p. 3 (V3/V4 motors), VESC configs `si_motor_poles = 32` |
| Phase angle | 120° | QS manual p. 3 |
| Phase wires | yellow = U/A, green = V/B, blue = W/C | QS manual p. 1, Kelly manual |
| Hall sensors | 3 hall sensors, 5 V supply. **Two sensor sets** (each 3 halls + temperature sensor), one of them a spare | QS manual p. 1, Kelly manual |
| Sensor set 1 | Fitted with our own plug, in use. All 3 hall sensors measured intact | Etienne, 2026-09-30 |
| Sensor set 2 | Original QS plug (no matching counterpart), never connected, unchecked | Etienne, 2026-09-30 |
| Temperature sensor | **KTY83-122.** Measured 0.97 kΩ at ~25 °C (KTY83-122 nominal 1.0 kΩ; a PT1000 would be ~1.1 kΩ, a 10k NTC ~10 kΩ). VESC set to KTY83/122 shows plausible temperatures. Heating test (resistance must rise ~0.8 %/°C) *to be completed* | QS manual p. 3, Etienne's measurement and VESC Tool session 2026-09-30 |
| Waterproofing | IP65 (hub motors) | QS manual p. 5 |
| QS temperature limits (V2/V3/V4) | 130 °C inside the motor (for 30 s) → limit current to 50 %; 145 °C → shut down, resume at 110 °C | QS manual p. 11 |
| Phase resistance R | ≈ 4.3–5.8 mΩ | VESC motor detection: this winch 4.34 mΩ ([260930_motor_config.xml](../../vesc/260930_motor_config.xml), measured 2024), Robert's 260 V4 5.8 mΩ ([old/vesc-configs/](../../old/vesc-configs/)) |
| Inductance L | ≈ 16–18 µH (Ld–Lq ≈ 4.7 µH) | same configs |
| Flux linkage λ | ≈ 25.6–26.1 mWb | same configs |
| Torque constant Kt | ≈ 0.63 Nm/A (derived: 1.5 × 16 pole pairs × λ). With the 0.43 m drum that is ≈ 3.4 A motor current per kg of line pull, consistent with the ~3.6 A/kg used for `myMaxPull` | Calculated estimate, not measured |
| KV (rpm/V) | *to be completed* | QS spec sheet or VESC Tool |
| Rated / max phase current, rated torque | *to be completed* | QS spec sheet |
| Rated voltage range, max rpm | *to be completed* (ordered as the 72 V version) | QS spec sheet |
| Weight | *to be completed* | |

## Sensor cable wiring (sensor set 1)

Confirmed by Etienne, 2026-09-30.

> ⚠ **The plug colours do not match the motor wire colours.** Red on the plug is a hall signal, green on the plug is +5 V. Always go by this table, not by colour conventions.

| Motor wire colour | Plug wire colour | Function |
|---|---|---|
| yellow | yellow | Hall A |
| green | white | Hall B |
| blue | red | Hall C |
| black | black | GND (halls and temperature sensor) |
| red | green | +5 V (hall supply) |
| silver (QS manual: "transparent") | blue | Temperature sensor (measured against GND) |

- Hall A/B/C follow the phase wire colours (yellow = A, green = B, blue = C). Connecting Hall A/B/C to H1/H2/H3 of the VESC is the natural choice. The assignment is not critical, because the VESC hall detection works out the order itself.
- Pin positions in the VESC sensor port and which plug colour goes to which VESC pin: *to be completed*. The Trampa manual in `vesc/` shows a newer controller revision, so check on the actual device.
- The QS manual warns that the hall sensors can be destroyed by static discharge above 5 V: don't touch the contacts without grounding yourself.

## VESC settings for this motor

The VESC configuration is documented in [vesc/readme.md](../../vesc/readme.md). That file is the authority. Motor-related values in the current config [vesc/260930_motor_config.xml](../../vesc/260930_motor_config.xml):

| Setting | Value | Note |
|---|---|---|
| `motor_type` | 2 (FOC) | |
| `l_current_max` / `l_current_min` | 250 A / −250 A | Unchanged since 2024 |
| `l_temp_motor_start` / `l_temp_motor_end` | 75 °C / 85 °C | Much more conservative than the QS limits above. Only works with the sensor cable connected |
| `foc_sensor_mode` | 2 (Hall) since 2026-09-30 | Hall table `255, 65, 118, 103, 199, 34, 173, 255`. See [WINCH-17](../../features/WINCH-17-hall-sensors-foc.md) |
| `m_motor_temp_sens_type` | 2 (KTY83/122) since 2026-09-30 | Was 0 (NTC 10k) → permanent over-temperature fault. The sensor cable must stay connected |
| `si_motor_poles` | 32 | = 16 pole pairs |
| `si_wheel_diameter` | 0.43 m (Etienne 2024) | Drum diameter, used for the line length |

## Mounting and maintenance notes (QS manual)

- Keep the phase wire outlet pointing **down** so water and dirt don't collect at the axle (p. 6–8).
- Don't seal the wire outlet with glue: the motor "breathes" through it when it heats up and cools down (p. 8).
- Don't carry the motor by the phase wires; it affects waterproofing (p. 5).
- Oil seal: check regularly; QS suggests replacing it after 18–24 months of use (p. 11). Status on this winch: *to be completed*.

## To be completed

- [ ] KV, rated/max phase current, rated torque, voltage range, max rpm, weight (QS spec sheet)
- [ ] Serial number, purchase date, exact order specification
- [ ] Heating test to confirm the KTY83-122 temperature sensor ([WINCH-17](../../features/WINCH-17-hall-sensors-foc.md))
- [ ] Condition of the spare sensor set 2 (original QS plug, unchecked)
- [ ] Pinout of the VESC sensor port vs. plug colours
- [ ] Oil seal status

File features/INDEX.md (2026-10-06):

# Feature Index

> Central roadmap for all hardware, firmware and documentation changes on the winch.
> One file per feature: `WINCH-NN-<slug>.md` (template: [TEMPLATE.md](TEMPLATE.md)).

## Status Legend
- **Idea**: noted, not yet specified
- **Planned**: scope, changes and test plan written
- **In Progress**: being built / coded / written
- **Bench Test**: built, being tested in the workshop (winch on the stand, no pilot)
- **Field Test**: being tested in real towing operation
- **Done**: tested and in use
- **Dropped**: decided against; code/docs archived where applicable

**Safety-relevant** = touches pull/brake behaviour, failsafe, autostop, the LoRa protocol or anything a pilot relies on. These always need Etienne's explicit confirmation and a bench test before a field test.

## Suggested order
**WINCH-01** → 02 → 03 → 04 → 16 → 08 → 05 + 06 + 07 (one flash, struct change) → 09 → rest

## Features

| ID | Feature | Type | Status | Priority | Safety | Depends | Spec |
|----|---|---|---|---|---|---|---|
| WINCH-01 | ⚠ Fix dangerous README rewind instruction (max. state 2) | Doc | Done | P0 | Yes | – | [WINCH-01](WINCH-01-fix-readme-rewind-instruction.md) |
| WINCH-02 | Sync repo with latest local code (other machine) | FW | Done | P0 | Yes | – | [WINCH-02](WINCH-02-sync-latest-local-code.md) |
| WINCH-03 | Source-file cleanup (one `.ino` per sketch) & drop PlatformIO | FW/Doc | Done | P0 | No | WINCH-02 | [WINCH-03](WINCH-03-source-cleanup-drop-platformio.md) |
| WINCH-04 | Archive cockpit monitor → `old/` | Doc/FW | Bench Test | P0 | No | WINCH-03 | [WINCH-04](WINCH-04-archive-cockpit-monitor.md) |
| WINCH-05 | Drop emergency line cutter | FW/Doc | Bench Test | P1 | Yes | WINCH-02, WINCH-03 | [WINCH-05](WINCH-05-drop-emergency-line-cutter.md) |
| WINCH-06 | Drop warning light (relay = fan only) | HW/Doc | Done | P1 | No | – | [WINCH-06](WINCH-06-drop-warning-light.md) |
| WINCH-07 | Automatic cooling fan by operating mode | FW | Bench Test | P1 | Yes | WINCH-05, WINCH-06 | [WINCH-07](WINCH-07-automatic-cooling-fan.md) |
| WINCH-08 | Autostop documentation & verification (poti, ADC, FW version) | Doc/VESC | Planned | P0 | Yes | WINCH-01, WINCH-16 | [WINCH-08](WINCH-08-autostop-docs-verification.md) |
| WINCH-09 | User & maintenance manual | Doc | Planned | P1 | Yes | WINCH-01, WINCH-08 | [WINCH-09](WINCH-09-user-maintenance-manual.md) |
| WINCH-10 | Add Trampa VESC 75/300 user manual to `vesc/` | Doc | Done | P2 | No | – | [WINCH-10](WINCH-10-vesc-75-300-manual.md) |
| WINCH-11 | New enclosure & cable management | HW | Idea | P1 | No | – | [WINCH-11](WINCH-11-enclosure-cable-management.md) |
| WINCH-12 | Remote case redesign + LiPo pouch cells | HW | Idea | P2 | No | – | [WINCH-12](WINCH-12-remote-case-lipo.md) |
| WINCH-13 | TX/RX pairing / encryption | FW | Idea | P3 | Yes | WINCH-02 | [WINCH-13](WINCH-13-tx-rx-pairing-encryption.md) |
| WINCH-14 | Pull-value calibration procedure | Doc | Idea | P2 | Yes | – | [WINCH-14](WINCH-14-pull-value-calibration.md) |
| WINCH-15 | Pin / board review (tech-debt list) | FW | Idea | P2 | Yes | WINCH-02 | [WINCH-15](WINCH-15-pin-board-review.md) |
| WINCH-16 | Line length & duty cycle stay at 0 (UART telemetry) | FW/VESC/HW | Planned | P0 | Yes | – | [WINCH-16](WINCH-16-uart-telemetry-zero.md) |
| WINCH-17 | Reconnect hall & motor temp sensors, FOC hall mode | HW/VESC/Doc | Bench Test | P1 | Yes | WINCH-16 | [WINCH-17](WINCH-17-hall-sensors-foc.md) |
| WINCH-18 | Potentiometer wiring & part spec (ADC2 manual mode) | HW/Doc | In Progress | P1 | Yes | – | [WINCH-18](WINCH-18-potentiometer-wiring.md) |
| WINCH-19 | Winch camera & line overwrap protection | HW | In Progress | P1 | Yes | – | [WINCH-19](WINCH-19-camera-overwrap-protection.md) |
| WINCH-20 | Pin toolchain & store libraries in the repo | FW/Doc | In Progress | P1 | Yes | – | [WINCH-20](WINCH-20-pin-toolchain-libraries.md) |
| WINCH-21 | Add CAD files of the winding gears (Fusion + STL) | HW/Doc | Planned | P2 | No | – | [WINCH-21](WINCH-21-gear-cad-files.md) |
| WINCH-22 | Over-voltage fault when braking (regen) | HW/VESC/Doc | Planned | P0 | Yes | – | [WINCH-22](WINCH-22-overvoltage-regen-braking.md) |
| WINCH-23 | VESC Tool user guide | Doc | In Progress | P1 | No | WINCH-17 | [WINCH-23](WINCH-23-vesc-tool-guide.md) |
| WINCH-24 | Printable checklist (packing, setup, before launch) | Doc | Planned | P1 | Yes | – | [WINCH-24](WINCH-24-printable-checklist.md) |
| WINCH-25 | Telemetry over the VESC CAN port (UART does not answer) | HW/FW/VESC | Idea | P3 | Yes | WINCH-16, WINCH-08 | [WINCH-25](WINCH-25-can-telemetry.md) |

<!-- Add features above this line -->

## Next Available ID: WINCH-26

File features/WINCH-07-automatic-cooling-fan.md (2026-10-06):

# WINCH-07: Automatic cooling fan by operating mode

**Status:** Bench Test
**Type:** FW
**Priority:** P1
**Safety-relevant:** Yes (LoRa struct change; a VESC overheating would cut power during a tow)
**Depends on:** WINCH-05, WINCH-06
**Created:** 2026-09-28 · **Last updated:** 2026-10-02

## Motivation
Today the transmitter turns the relay (fan) ON at startup, and a short press on the 3rd button toggles it. Manual toggling is unnecessary. The fan should simply run while the winch is working and stop afterwards.

## Known bug (diagnosed and fixed 2026-10-02)
**Cause:** the relay signal wire (yellow) was soldered to **GPIO15** instead of IO12. The sketch never drives GPIO15; its internal boot pull-up only made the module LED glow, too weak to switch the transistor, so the relay never clicked. Etienne resoldered it to IO12 (2026-10-02): the relay now clicks and the fan runs. Fan wiring on the load side: COM + NO (correct for `RELAY_ACTIVE_HIGH = true`). Relay module: Songle SRD-05VDC-SC-C, `+` → 5V, `-` → GND, `S` → IO12.
**Fan does not switch on, although the receiver OLED shows "Fan/Light ON"** after the remote has connected (reported by Etienne, 2026-09-28).

The OLED text only shows the software variable `relay`, so the receiver has received `relay = true` and writes IO12 HIGH every loop. The fault is therefore most likely between IO12 and the fan, not in the LoRa logic. Not yet diagnosed. Candidates to check (bench, winch not in use):
- [ ] **Relay module polarity:** many relay modules are *active-low* (IN = LOW → relay on). Then HIGH would mean OFF. Hint: does the fan run right after the receiver boots, *before* the remote is connected (IO12 LOW then)? Does the module's LED light up?
- [ ] **Trigger level:** a 5 V relay module may not switch reliably with the ESP32's 3.3 V signal. Measure IO12 against GND (expect ~3.3 V when "ON") and check whether the relay clicks.
- [ ] **Relay module supply:** 5 V and GND actually present at the module.
- [ ] **Load side:** fan wired through COM/NO (not NC), fan supply present, fan itself OK (test directly on its supply).
- [ ] **IO12 strapping pin** (see WINCH-15): check nothing on the module pulls IO12 in a way that interferes.
- [ ] Wiring vs. README "PIN Setup Receiver" note (white = signal → IO12, red → 5V, black → GND).

Whatever the cause, the new fan logic below must drive the relay with the correct polarity (possibly a named constant for active-high/low). Bench test must confirm the fan **actually runs**, not only the OLED text.

## Scope
- **Fix the bug above** (hardware/wiring and/or output polarity in `receiver.ino`).
- **Receiver** decides alone:
  - Relay (IO12) **ON** as soon as a pull state (`currentState >= 1`) is active.
  - Relay **OFF** only after `FAN_RUN_ON_MS` (**120 s**, a named constant at the top of `receiver.ino`) without any pull state. The run-on lets the VESC cool down and avoids flapping during step tows (default pull ↔ brake).
  - Failsafe states count as pull (fan stays on).
- **Transmitter:** remove the relay toggle (3rd-button short press) and the `relay` field from `LoraTxMessage` (same struct change as WINCH-05, one flash for both).
- **Receiver:** remove the `relay` field; OLED shows "Fan ON/OFF".
- README.md: describe the automatic behaviour, update the IO12 pin description.

## Out of scope
- Temperature-based fan control (possible later idea: also keep the fan on while motor/MOSFET temperature from UART is above a threshold).
- Removing the 3rd button hardware.

## Changes
- **Firmware transmitter:** remove relay handling and field.
- **Firmware receiver:** new fan logic, remove field.
- **Docs:** README.md.

## Test plan
### Bench
- [x] Known bug diagnosed and fixed: relay signal was on GPIO15, now IO12; relay clicks, fan runs (Etienne, 2026-10-02).
- [x] Power-on in soft brake: fan OFF (Etienne, 2026-10-03, new firmware; the 2026-10-02 "fan on at connect" was the old firmware).
- [x] State 1 → fan ON immediately (2026-10-03).
- [x] Back to brake: fan stays on for about 120 s, then OFF (2026-10-03).
- [ ] Brake ↔ pull within 120 s: fan stays on without switching off.
- [ ] Transmitter off during pull (failsafe): fan stays on.
- [x] Receiver boots normally with the relay connected to IO12 (strapping pin, see WINCH-15): the receiver is powered by the VESC and boots immediately when the VESC is switched on (Etienne, 2026-10-02).
### Field
- [ ] Full tow session: fan behaviour as expected, no VESC temperature problems.

## Open questions
- [x] Is 60 s run-on right, or longer (e.g. 120 s) after hard tows? → 120 s (Etienne, 2026-09-30).

## Decision log
| Decision | Rationale | Date |
|---|---|---|
| Fan ON while pull state active, OFF after run-on | Etienne's choice: no manual toggling; run-on for cooling and against flapping during step tows | 2026-09-28 |
| Logic lives in the receiver only | Receiver knows the actual state, including failsafe; no protocol field needed | 2026-09-28 |

## Log
- 2026-09-28: created
- 2026-09-28: known bug added: fan does not run although OLED shows "Fan/Light ON" (Etienne). Diagnosis checklist added.
- 2026-09-30: implemented in `receiver.ino`: fan ON while `currentState >= 1` (incl. failsafe), OFF after `FAN_RUN_ON_MS` = **120 s** (Etienne's choice) without pull state, OFF after power-up. Relay polarity as constant `RELAY_ACTIVE_HIGH` (default `true` = previous behaviour; the known bug is not diagnosed yet, set to `false` if the relay module turns out to be active-low). OLED: "Fan ON", "Fan ON (off in … s)", "Fan OFF". Transmitter: relay toggle and `relay` field removed. Compiles; not flashed, not bench-tested. Not covered: manual rewinding with the potentiometer while the remote is in brake keeps the fan off (the receiver doesn't know about poti mode).
- 2026-10-02: known bug diagnosed and fixed: relay signal wire was on GPIO15, resoldered to IO12 (Etienne). Relay clicks, fan runs. Receiver (powered by the VESC) boots normally with the relay on IO12. Open: the fan switched on as soon as the remote connected, which points to the old firmware still being flashed (see bench test plan).
- 2026-10-02: fan behaviour after release reviewed (code reading only, Etienne's observation): after release the remote stays in state 1 or 2 while the VESC AutoStop holds the drum. The receiver does not see AutoStop (it only follows the remote's state), so the fan keeps running until the remote goes to brake (then 120 s run-on) or is switched off (20 s failsafe defaultPull → soft brake, then 120 s run-on, ≈ 140 s in total). Decision proposal: keep it this way. While AutoStop holds the drum the VESC drives 18 A brake current into the motor, so cooling is useful. Detecting AutoStop in the receiver (tachometer/duty cycle over UART) would depend on WINCH-16 and would be a change to safety-relevant code; not planned. Etienne's observation after switching the remote off: OLED shows "P 1" with -20 kg, then "B -1". Interpretation (not verified): the failsafe sets state 1, but the receiver's own autostop taper (`tachometer < 10` → `hardBrake = -20`) overrides the pull value; after 20 s the failsafe goes to soft brake. If correct, the UART tachometer is not stuck at 0 any more (relevant to WINCH-16).
- 2026-10-02: confirmed by Etienne: transmitter and receiver still run the **old** firmware (pre WINCH-07). This explains the fan switching on at connect. The WINCH-07 logic has not been flashed or bench-tested yet.
- 2026-10-03: new firmware flashed on both boards. Bench (desk, no motor), Etienne: TX and RX connect, LoRa works, buttons work, fan starts and stops as intended. Still open: brake ↔ pull within 120 s, failsafe with the remote switched off.

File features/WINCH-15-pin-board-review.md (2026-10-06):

# WINCH-15: Pin / board review (tech-debt list)

**Status:** Idea
**Type:** FW
**Priority:** P2
**Safety-relevant:** Yes
**Depends on:** WINCH-02 (review the code that is actually in use)
**Created:** 2026-09-28 · **Last updated:** 2026-09-28

## Motivation
While reading the code for CLAUDE.md, several questionable spots came up. They work in practice today, but should be checked deliberately instead of being "fixed" by accident:

- `#define RST 14` (LoRa reset) collides with `VESC_RX 14` (receiver) and `BUTTON_THREE 14` (transmitter). On the TTGO LoRa32 V2.1_1.6 the LoRa reset is probably GPIO23.
- IO12 is an ESP32 strapping pin (flash voltage). It is used for the relay (receiver) and BUTTON_DOWN (transmitter). An external pull-up at boot can prevent booting.
- `LoRa.begin(868E6)` is hardcoded; the `BAND` define is unused.
- Failsafe comment says 10 s; the code uses 20 s. Decide which is intended and align the comment (not the timing) unless Etienne decides otherwise.
- Receiver autostop tachometer thresholds (2–40) vs. the VESC patch (1500 ≈ 15 m): different units, and the receiver taper may never trigger.
- Line length reported ~0.7× too short (Etienne's observation; VESC settings seem correct).

## Approach
Check each item against the board pinout and real behaviour, then decide per item: leave it and document it, fix the comment, or fix the code (as its own safety-relevant change with a bench test).

## Log
- 2026-09-28: created as idea
- 2026-10-03: receiver supply documented (README "Receiver wiring harness"): the VESC powers the receiver through the board's small 2-pin **battery** connector (on the transmitter it goes to an 18650 cell). Open: which voltage the VESC delivers there. That input is designed for a single Li-ion cell (about 3.0–4.2 V) and feeds the onboard charger; if it gets 5 V, check that this is within the board's limits or move the supply to the 5V pin.
- 2026-10-03: **LoRa reset pin fixed in both sketches: `RST 14` → `RST 23`** (Etienne asked to review and correct the code before reflashing). The board pinout (doc/LilyGO-…-pinout….jpg, T3_V1.6.1) shows LoRa RST = GPIO23. On the receiver, IO14 is also `VESC_RX`, and `LoRa.begin()` set it as an output (HIGH) after `Serial1.begin()`. On the transmitter IO14 is unused since WINCH-05. Safety-relevant (LoRa init): bench test on the desk before using it at the winch. Compiles (arduino-cli, esp32 2.0.15); not flashed, not tested.
- 2026-10-03: unused `myMaxPull = 85` and the four `…PullScale` variables removed from `receiver.ino` (never referenced; the pull states are computed in the transmitter only). No behaviour change. Compiles.
- 2026-10-03: bench: with `RST 23` both boards start, LoRa link works (Etienne). The fix is confirmed on the bench.

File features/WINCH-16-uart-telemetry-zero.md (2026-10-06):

# WINCH-16: Line length & duty cycle stay at 0 (UART telemetry)

**Status:** Planned
**Type:** FW / VESC (read-only) / HW
**Priority:** P0
**Safety-relevant:** Yes (the receiver-side autostop taper uses the UART tachometer; the pilot/operator relies on the line length)
**Depends on:** –
**Created:** 2026-09-28 · **Last updated:** 2026-10-03

## Motivation
The transmitter's bottom OLED line (`<line length>m| <duty cycle>%`) always shows 0 / 0 (Etienne, 2026-09-28). The values come from the VESC via UART to the receiver, then via LoRa ack to the transmitter. The motor's temperature sensor and hall sensors are currently not connected to the VESC. Unclear whether (a) the UART link is broken, or (b) UART works but the VESC reports 0.

This must be clarified before WINCH-08 (autostop verification), because autostop depends on the tachometer: the receiver taper directly via UART, the VESC autostop via the VESC's internal tachometer.

## What the code does (read, not tested)
- Receiver reads the VESC every 20 loops (`vescUART.getVescValues()`, `Serial1` 115200 baud, RX = IO14, TX = IO2). If the read fails, the old values stay, and they start at 0.
- Ack to the transmitter: `tachometer = abs(tacho) / 1000` (→ unit of 10 m, displayed as `×10 m`), `dutyCycleNow = abs(duty × 100)` %.
  - So the line length shows **0 until about 10 m** are unwound (if 1500 counts ≈ 15 m, as in the patch).
  - Duty cycle is **0 whenever the motor isn't turning**, by definition.
- Battery % (`B: xx%`) and motor temperature (`T: yy C`) come through **the same UART read** and alternate in the top line of the transmitter OLED.

## Findings so far (Etienne, 2026-09-28)
- **UART works:** the transmitter shows `B: 45%`. Battery % comes from the same UART read (`COMM_GET_VALUES`) as tachometer and duty cycle.
- **History of the sensor cable:**
  - Before: wiring was a mess and one wire of the sensor cable (hall or motor temp) was broken. Line length **still showed and worked** then.
  - New case, wiring cleaned up, sensor cable (6 wires: hall sensors + motor temp) connected with the broken wire fixed → **VESC showed an error** → sensor cable unplugged again. Currently: no hall / temp sensors connected.
- **Tachometer stopped about two days ago (~2026-09-26):** turning the motor with the potentiometer (manual mode) used to make the line length count up; now it stays 0. Duty cycle also stays 0.
- **Autostop still seems to work.**

### Interpretation (from reading the patch, not verified)
- The patch applies autostop in normal PPM mode whenever `abs(tachometer) < 1500`: 18 A brake, PPM input ignored (`vesc_ppm_auto_stop.patch` lines 45-48). If the VESC-internal tachometer were really stuck at 0, the winch would **only brake and never pull** in PPM mode.
- So if the winch still pulls normally *and* autostop still triggers, the VESC-internal tachometer probably still counts, and only the value that reaches the receiver/transmitter is 0. That would point to parsing / data path (e.g. VescUart library vs. firmware packet layout) rather than to the missing hall sensors.
- Counter-check needed: if tachometer *and* duty cycle are 0 but voltage is fine, the packet is received but some fields are read wrongly or not updated.

### Questions for the next debug session
- [ ] What changed around two days ago? Receiver reflashed? Arduino libraries updated (VescUart!)? VESC reflashed or reconfigured (e.g. motor detection / sensor mode changed while connecting the sensor cable)?
- [x] Which error did the VESC show with the sensor cable connected (fault code in VESC Tool)? → `FAULT_CODE_OVER_TEMP_MOTOR`, wrong temperature sensor type (2026-09-30, see Log).
- [ ] How exactly was "autostop still works" observed (PPM mode or poti mode, which line length)? Note: in poti mode autostop is only active if ADC1 > 3 V (see WINCH-08).
- [ ] In PPM mode (remote), does the winch pull normally after line has been pulled out, or does it only brake?
- [ ] What does the motor temperature `T:` show (expected: 0 or an implausible value without sensor)?
- [ ] VESC Tool → Realtime data: tachometer and duty cycle while the motor turns. Do they count there?

## Scope: diagnosis first (no code / VESC changes)
1. [x] **Top line of the transmitter OLED:** does `B:` show a plausible battery % (not 0)? → Yes, 45 % (2026-09-28). Step 2 not needed for now.
   - Yes → UART works; the zeros are a VESC-side / measurement issue (continue at 3).
   - No (`B: 0%`) → UART read fails (continue at 2).
2. [ ] **If UART fails:**
   - Wiring: VESC COMM TX → receiver IO14, VESC COMM RX → receiver IO2, common GND.
   - VESC Tool → App settings: app = "PPM and UART", UART baud 115200. (Backups `old/vesc-configs/240601_app_config.xml` / `vesc_app_config.xml` have `app_to_use = 4` = PPM + UART, 115200. To confirm on the real VESC.)
   - Known pin collision: `RST 14` (LoRa reset) = `VESC_RX 14`. `LoRa.begin()` runs *after* `Serial1.begin()` and may reconfigure IO14. Suspect, not confirmed (see WINCH-15).
   - Optional: enable `vescUART.setDebugPort(&Serial)` / the commented-out serial prints in `receiver.ino` for a bench session (temporary, not committed).
3. [ ] **If UART works but values stay 0:**
   - Check with the motor actually turning under pull (states ≥1, line being pulled in/out). At standstill 0 / 0 is expected.
   - VESC Tool → Realtime data: does the tachometer change while the drum turns (a) under pull, (b) when line is pulled out by hand under soft brake?
   - Hall sensors: June 2024 backup (now `old/vesc-configs/240601_motor_config.xml`) has `foc_sensor_mode = 0` (sensorless; hall mode active since 2026-09-30, WINCH-17); the older configs have `2` (hall). In sensorless FOC the tachometer is counted by the observer **while the motor is driven**; at low speed / by hand it may not count. To confirm on the real VESC which mode is active.
4. [ ] Record the result here, then decide the fix (wiring, pin change in `receiver.ino` → safety-relevant, or reconnecting hall sensors).

## Out of scope
- VESC firmware / config changes (frozen; only if Etienne explicitly decides so).
- The known ~0.7× line-length offset and the tachometer unit mismatch (receiver taper 2–40 vs. patch 1500) → WINCH-08, unless the diagnosis shows they are the same problem.

## Changes
- To be decided after diagnosis.

## Test plan
### Bench (workshop, no pilot)
- [ ] Transmitter shows plausible battery % and motor temp (or a known "no sensor" value).
- [ ] Line length on the transmitter increases while line is unwound, and returns towards 0 when rewound.
- [ ] Duty cycle shows a non-zero value while the drum turns.

## Open questions
- [x] Did line length / duty cycle ever work with the current setup? → Yes, until about two days ago, even with a broken sensor wire.
- [x] Why are hall / temp sensors disconnected? → VESC showed an error when the repaired sensor cable was connected. Reconnecting depends on that error (see questions above).
- [ ] Does the VESC's own autostop still work without hall sensors? → verify in WINCH-08.

## Decision log
| Decision | Rationale | Date |
|---|---|---|
| Diagnose before WINCH-08 | Autostop verification needs a working, trustworthy tachometer | 2026-09-28 |

## Log
- 2026-09-28: created (reported by Etienne).
- 2026-09-28: first findings added: UART works (B 45 %), tacho stopped ~2 days ago, sensor cable unplugged after VESC error, autostop seems to still work. Debugging postponed.
- 2026-09-29: reconnecting the hall / temperature sensors and switching to FOC hall mode split out as [WINCH-17](WINCH-17-hall-sensors-foc.md); background in vesc/readme.md.
- 2026-09-30 (VESC Tool session with Etienne, VESC Tool 3.01, FW 5.3):
  - **The VESC error with the sensor cable connected was `FAULT_CODE_OVER_TEMP_MOTOR`**: `m_motor_temp_sens_type` was set to NTC 10k, but the motor has a KTY83-122 (0.97 kΩ at ~25 °C). As NTC this reads ~100 °C, above the 75/85 °C motor limits → fault, no current. Fixed by setting the sensor type to KTY83/122 (see WINCH-17). Without the sensor cable the input is open and now reads as extremely hot, so the cable must stay connected.
  - **The VESC-internal tachometer counts:** `faults` output showed `Tacho: 15914`, Realtime Data `Tac: 14566` / `Tac ABS: 15580` after turning the drum with the potentiometer. So the zeros are on the UART / receiver / LoRa side, not in the VESC.
  - **Transmitter OLED shows `30m| 85%` and does not update** (Etienne): at least one telemetry packet with tachometer and duty cycle got through at some point, then the values froze. Keep for debugging: frozen values rather than zeros suggest that UART reads (`getVescValues()`) fail after a first success, or the ack stops carrying new data. Lead to check first: the pin collision `RST 14` (LoRa reset) = `VESC_RX 14` in `receiver.ino`.
- 2026-10-02: according to the board pinout in `doc/` (LilyGO T3 V1.6.1), the LoRa reset is **GPIO23**, not 14. With `RST 14`, the LoRa library most likely switches IO14 to a plain output during `LoRa.begin()` (it pulses the reset pin), which runs *after* `Serial1.begin()`. The UART RX pin would then no longer receive and would drive against the VESC's TX. Not verified on the board; strong suspect for the frozen telemetry. A wiring check with the old firmware comes first (WINCH-05, "Before flashing"). Also: the board's microSD slot uses IO13/14/15/2, so no card may be inserted. Etienne: no card in the receiver, none planned.
- 2026-10-02 (bench, controller on the desk, old firmware on TX/RX): UART wiring checked by Etienne. IO14 (receiver RX) → blue wire → green wire → VESC COMM **TX**: correct. IO2 (receiver TX) → white wire, soldered to a green wire → VESC COMM **RX**: correct routing. **An orange wire measures open circuit (OL) end to end: broken.** Which signal it carries is still to be confirmed. A broken or intermittent UART wire fits the frozen values (`30m| 85%`): reads succeed while the wire makes contact, then fail and the receiver keeps sending the last values. Next: replace the wire, then check that `B:` / `T:` and line length update.
- 2026-10-02: correction: the orange wire is the IO2 → VESC **RX** line (white wire from IO2 to the orange wire of the pre-made COMM plug). Etienne found damaged insulation: several wires of the harness were stuck together. After pulling them apart the continuity test passes. Likely cause: damaged insulation / short or intermittent contact on the receiver → VESC request line (without the request the VESC never answers, so the receiver keeps the last values). Plan: re-insulate / repair the harness first, check that adjacent wires are isolated from each other, then test UART.
- 2026-10-03: harness repaired and re-insulated (Etienne); telemetry still does not work. Wiring confirmed: VESC RX ← white (IO2), VESC TX → blue (IO14). VESC app config checked in `260930_app_config.xml`: `app_to_use = 4` (PPM and UART), `app_uart_baudrate = 115200`, both fine. Main suspect now: **IO14 is both `VESC_RX` and LoRa `RST`**. `Serial1.begin()` routes IO14 to UART RX, then `LoRa.begin()` sets IO14 as OUTPUT and leaves it HIGH, so the receiver may never see the VESC's answer. The board pinout ([doc/LilyGO-TTGO-T3-LoRa32-433MHz-V2.1.6-ESP32-pinout-1500x1500w.jpg](../doc/LilyGO-TTGO-T3-LoRa32-433MHz-V2.1.6-ESP32-pinout-1500x1500w.jpg)) confirms LoRa RST = **GPIO23**. Open: why it worked earlier (receiver reflashed around 2026-09-26, possibly with a different ESP32 core?). Proposed diagnostic: old receiver code (compatible with the flashed transmitter) with only `RST 14` → `RST 23`, bench only, needs Etienne's OK.
- 2026-10-03: Etienne: the receiver was last flashed long ago and telemetry still worked afterwards, so the `RST 14` collision is probably not the only cause (the harness short may also have played a part). Code changes before reflashing both boards with the current repo version: `RST 23` (see WINCH-15); receiver prints UART diagnosis on the USB serial monitor (115200 baud) every VESC read: `VESC ok: <V> V, tacho <n>, duty <d>, motor <t> C` or `Failed to get data from VESC!`. Failsafe comment corrected (20 s, code unchanged). Both sketches compile; not flashed, not tested.
- 2026-10-03: new firmware flashed (RST 23, serial diagnosis); LoRa link works. Etienne asked for the telemetry on the receiver OLED as well: new bottom line `Tac <raw tachometer counts> D <duty cycle %> ok|ERR` (`ERR` = last `getVescValues()` failed, the values shown are then the last good ones). Shows directly on the receiver whether the UART data arrives, independent of the LoRa ack. Display only, no change to pull/brake logic. Compiles; not flashed yet.
- 2026-10-03: receiver OLED shows `ERR` (new display line): `getVescValues()` fails, while VESC Tool over USB shows Tac and duty. Cross-check by Etienne: a **second TTGO board** with a **new JST cable** (5V, GND, TX, RX) and the same receiver code also shows `ERR`, so the original receiver board and harness are unlikely to be the (only) cause. Multimeter: VESC COMM 5V → TX ≈ 1.7 V and 5V → RX ≈ 1.7 V, i.e. both ≈ 3.3 V against GND (assuming 5.0 V): normal UART idle level, no obviously dead or shorted pin. Remaining suspects: VESC UART not active / wrong setting in the live config, VESC UART damaged in a way the idle level does not show, or software (sketch / VescUart library). Next: check App Settings live, then the USB↔UART passthrough test with VESC Tool on the spare board.
- 2026-10-03: measured against GND: VESC TX and RX both 3.3 V (normal idle). VESC App Settings live (screenshot): App to Use = PPM and UART, Enable Permanent UART = True, timeout 1000 ms / 10 A brake; identical to all stored app configs since 2024 (`permanent_uart_enabled = 1`, `app_to_use = 4`, baud 115200), so no config change explains the failure. UART baud rate in the live UART tab still to be confirmed. VescUart 1.0.1 reviewed: `getVescValues()` returns false on timeout (100 ms), wrong start byte, CRC mismatch or payload ≤ 55 bytes; the library prints which one when a debug port is set. Next: spare board with `vescUART.setDebugPort(&Serial);` enabled (local diagnostic build, not committed), and/or the passthrough test.
- 2026-10-03: debug output on the spare board (`setDebugPort` enabled locally): every cycle `Package to send: 2 1 4 64 132 3` (correct COMM_GET_VALUES frame) followed by `Timeout`. **Not a single byte comes back from the VESC.** No motor connected is not the cause (the VESC answers COMM_GET_VALUES without a motor; VESC Tool over USB shows values). Next: loopback on the spare board (IO2 ↔ IO14 bridged at the cable end, VESC unplugged): expected debug output `End of message reached!` with matching SRC values, which would prove ESP32 pins + new cable and point to the VESC COMM UART.
- 2026-10-03: **loopback passed:** IO2 and IO14 bridged at the VESC end of the new JST cable → `End of message reached!`, `SRC received 16516 = SRC calc 16516`, own frame `2 1 4 64 132 3` received (then `Failed` as expected: 1-byte payload). **ESP32 UART pins and the new cable work.** With the VESC connected not a single byte comes back, so the fault is on the VESC side: TX/RX swapped at the COMM plug, or the VESC COMM UART does not receive / answer (possibly damaged by the harness short). Next: identify which COMM pin is the VESC output (TX) with a resistor load test, no swapping of outputs.
- 2026-10-03: VESC COMM TX/RX labelling confirmed correct by Etienne (and it used to work with this wiring). **Debugging paused (Etienne):** line length and duty cycle on the remote are not essential. Conclusion so far: ESP32 side and cables are fine, the VESC COMM UART does not answer (cause unknown, possibly damage from the harness short). Consequence while telemetry is missing: battery % / motor temp / line length / duty cycle on the remote are not updated, and the **receiver autostop taper is inactive** (it needs `tachometer > 2`); the VESC firmware autostop is independent of this. Possible alternative: telemetry over the unused VESC CAN port ([WINCH-25](WINCH-25-can-telemetry.md), idea). Temporary debug line re-commented in `receiver.ino`.

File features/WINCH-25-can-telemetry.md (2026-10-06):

# WINCH-25: Telemetry over the VESC CAN port

**Status:** Idea
**Type:** HW / FW / VESC
**Priority:** P3
**Safety-relevant:** Yes (brings the tachometer back to the receiver, which re-activates the receiver autostop taper; needs a VESC config change)
**Depends on:** WINCH-16, WINCH-08
**Created:** 2026-10-03 · **Last updated:** 2026-10-03

## Motivation
The VESC COMM UART no longer answers (WINCH-16): ESP32 pins and cables are proven fine by a loopback test, but the VESC sends nothing back. The VESC has an unused CAN port. Etienne asked whether the telemetry could go through it instead.

## How it would work (not built, not tested)
- CAN is a different bus, not UART: the UART link cannot simply be "rerouted" to the CAN port.
- The VESC can **broadcast status messages on CAN** by itself (App Settings → General → *Can Status Message Mode*, today `CAN_STATUS_DISABLED`, CAN baud 500K). These messages contain, among others, RPM, current and duty cycle (status 1), temperatures (status 4), tachometer and input voltage (status 5). The receiver would only listen, no requests needed.
- The ESP32 has a built-in CAN controller (TWAI, included in the esp32 core 2.0.15, no extra library). It needs an external **3.3 V CAN transceiver module** (e.g. SN65HVD230) on two free GPIOs, wired CANH/CANL/GND to the VESC CAN port, with 120 Ω termination at the ends of the bus.

## Scope (if pursued)
- Hardware: transceiver module, wiring, termination.
- VESC: enable CAN status messages (**VESC config change: only with Etienne's explicit decision**, config is frozen by default).
- Receiver: read status 1/4/5 frames instead of `getVescValues()`, same values into the LoRa ack.

## Out of scope
- Sending commands to the VESC over CAN (pull/brake stays on PPM).

## Open questions
- [ ] Does the receiver autostop taper (raw tachometer 2–40) make sense once the tachometer arrives again? Units vs. the patch (1500 ≈ 15 m) are unclear (WINCH-08). Decide before re-enabling.
- [ ] Ask Trampa whether the 75/300 R3 COMM UART can be repaired, or has a second UART, before building this.

## Decision log
| Decision | Rationale | Date |
|---|---|---|

## Log
- 2026-10-03: created as an idea after WINCH-16 debugging was paused (Etienne's question about the CAN port).

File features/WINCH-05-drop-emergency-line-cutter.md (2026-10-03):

# WINCH-05: Drop emergency line cutter

**Status:** Bench Test
**Type:** FW / Doc
**Priority:** P1
**Safety-relevant:** Yes (changes the LoRa struct and the 3rd-button behaviour, which includes a forced hard brake)
**Depends on:** WINCH-02, WINCH-03
**Created:** 2026-09-28 · **Last updated:** 2026-10-02

## Motivation
Bernd's line cutter was physically mounted in the new frame (winter 24/25) but never wired, and there is no plan to do so. The servo code, the 3rd-button long/double click and the `servo` field in the LoRa message are dead weight.

## Scope
- **Transmitter:** remove the `servo` variable, the 3rd-button long click (servo + hard brake) and double click (servo reset), and the `servo` field in `LoraTxMessage`.
- **Receiver:** remove the ESP32Servo include, the `Servo` object, `servoPin` 15 and its handling, the `servo` field in `LoraTxMessage`, and the "Line Cutter" OLED line.
- README.md: remove the line cutter sections, the IO15 pin description, ESP32Servo from the library list, the old "Done ToDo" mention.
- Bundle with WINCH-07 into **one** struct change and one flash of TX + RX.

## Out of scope
- Physically removing the cutter from the frame (Etienne's call).
- A replacement emergency function. Hard brake remains available via the normal buttons.

## Changes
- **Firmware transmitter / receiver:** see scope. `LoraTxMessage` must stay byte-identical in both sketches.
- **Docs:** README.md.

## Before flashing (old firmware still on both boards)

> **Status 2026-10-03:** both boards were flashed with the new firmware **without** this backup (Etienne's deliberate decision). The image of the old firmware is gone. Fallback if the new version misbehaves: build the old sketches from git (`git show 40a043e:receiver/receiver.ino`, `git show 40a043e:transmitter/transmitter.ino`, the state before WINCH-05/06/07) and flash both boards together. That rebuild is close to the old state but not guaranteed to be byte-identical (libraries / core used back then are unknown).

Do these two steps first, with the winch **not in use** (no pilot, line not under tension). Plugging USB into the receiver resets the ESP32. The PPM signal stops, and after 1 s the VESC brakes with its timeout brake current (10 A).

### 1. Back up the current firmware of both boards (esptool)
This is a full image of each board's flash memory, i.e. the old, field-proven state. If the new version misbehaves, both boards can be put back exactly as they were.

esptool comes with the esp32 core of the Arduino IDE:
- Path (Arduino IDE 2, Windows): `%LOCALAPPDATA%\Arduino15\packages\esp32\tools\esptool_py\<version>\esptool.exe`. Look in the `esptool_py` folder for the version number.
- If the path is unclear: in the Arduino IDE enable *File → Preferences → Show verbose output during: upload*, then upload any sketch once. The log shows the full esptool path. Do this with a spare board, not with the winch boards.
- COM port: Arduino IDE *Tools → Port*, or Windows Device Manager → "Ports (COM & LPT)". Plug in one board at a time so the port is unambiguous.

PowerShell, one board at a time (replace `<version>`, `COM5` and the date):
```powershell
$esptool = "$env:LOCALAPPDATA\Arduino15\packages\esp32\tools\esptool_py\<version>\esptool.exe"
mkdir "$env:USERPROFILE\Documents\winch-firmware-backups" -Force
cd "$env:USERPROFILE\Documents\winch-firmware-backups"

# 1. Check the connection and the flash size (expected: 4MB)
& $esptool --chip esp32 --port COM5 flash_id

# 2. Read the whole flash (4 MB = 0x400000; use 0x800000 if flash_id reports 8MB)
& $esptool --chip esp32 --port COM5 --baud 460800 read_flash 0 0x400000 receiver_2026-10-xx.bin

# 3. Check that the file matches the board
& $esptool --chip esp32 --port COM5 --baud 460800 verify_flash 0 receiver_2026-10-xx.bin
```
Repeat with the transmitter (`transmitter_2026-10-xx.bin`). Each file is about 4 MB.
- Keep the backups **outside the repo** (e.g. the folder above, plus a copy on a USB stick or in the cloud). They are full flash images; do not commit them.
- If esptool can't connect: close the Arduino IDE serial monitor (it blocks the port), try `--baud 115200`, check the USB cable (some cables only charge).

**Restore** (only if the new version has to be rolled back), per board:
```powershell
& $esptool --chip esp32 --port COM5 --baud 460800 write_flash 0 receiver_2026-10-xx.bin
```
⚠ Always restore **both** boards: the old and the new firmware use different LoRa packet sizes and do not work together.

### 2. Check the wiring with the old firmware (baseline)
The fan relay doesn't switch (WINCH-07) and the telemetry freezes (WINCH-16). Both could be wiring problems. Check the wiring while the old firmware is still running, so a later fault is clearly due to either the hardware or the new code.

**Receiver, expected wiring according to the code** (identical in the old and new version, except IO15):

| ESP32 pin | Function in code | Should go to | Found (wire colour, OK?) |
|---|---|---|---|
| IO13 | PPM output | VESC "Servo"/PPM port, signal | |
| GND | PPM ground | VESC "Servo"/PPM port, GND | |
| IO14 | UART RX (`VESC_RX`) | VESC COMM **TX** | |
| IO2 | UART TX (`VESC_TX`) | VESC COMM **RX** | |
| GND | UART ground | VESC COMM GND | |
| IO12 | Relay signal | Relay module IN (white wire) | |
| 5V | Relay supply | Relay module VCC (red wire) | |
| GND | Relay ground | Relay module GND (black wire) | |
| IO15 | Line cutter servo (old firmware only) | nothing (never wired) | |
| ? | Receiver power supply | ? | |

The LoRa module and the OLED are wired on the board itself (no external wires). According to the pinout image in `doc/`, the board's LoRa reset is **GPIO23**. The code uses `RST 14`, i.e. the UART RX pin (see WINCH-16).

**Transmitter:** IO15 → UP button → GND, IO12 → DOWN button → GND, IO14 → 3rd button → GND (old firmware only).

Checks on the receiver:
- [x] **No microSD card in the board's card slot.** The slot uses IO13, IO14, IO15 and IO2, the same pins as the PPM output and the UART. → Confirmed, no card, none planned (Etienne, 2026-10-02).
- [ ] Fill in the table above. Take a photo of the receiver wiring.
- [ ] **UART, power off, multimeter in continuity mode:** IO14 ↔ VESC COMM TX, IO2 ↔ VESC COMM RX, GND ↔ VESC COMM GND. TX and RX must be **crossed** (TX to RX). Check crimps and that the JST plug is fully seated.
- [ ] **UART, running:** turn the drum with the potentiometer, compare `Tac` in VESC Tool (Realtime Data) with the line length on the transmitter OLED. Gently wiggle the UART wires and plugs: if the transmitter display changes or unfreezes, it's a contact problem.
- [ ] **Relay:** with the old firmware, a short press on the 3rd button of the remote toggles the relay. Use this to work through the relay checklist in WINCH-07 (voltage at IO12 against GND, module LED, relay click, fan on COM/NO).

Record the results in WINCH-07 (relay) and WINCH-16 (UART).

## Test plan
### Bench
- [ ] TX and RX flashed as a pair; link established (RSSI shown on both OLEDs).
- [ ] All states −2…5 reachable, receiver shows the correct state/kg.
- [ ] Failsafe: switch off TX during pull state → default pull after 1.5 s, soft brake after 20 s.
- [ ] Old TX + new RX (mismatched sizes) do **not** control the winch. Expected: packets ignored. Document the result.
### Field
- [ ] Normal tow session without anomalies.

## Open questions
- [ ] Does the 3rd button stay physically on the remote (unused), or is it removed (WINCH-12)?

## Decision log
| Decision | Rationale | Date |
|---|---|---|
| Line cutter is not implemented | Experience: not needed, adds complexity; never wired | 2026-09-28 |

## Log
- 2026-09-28: created
- 2026-09-30: implemented together with WINCH-06/07 (one flash). Transmitter: 3rd button (IO14), servo variable, `LineCutter()`/`setServo()` and the `servo` field removed. Receiver: ESP32Servo, servo object/pin 15 and the "Line Cutter" OLED line removed. `LoraTxMessage` is now 3 bytes (was 5); `static_assert`s in both sketches check 3/4 bytes. Additional safety fix: the admin transmitter's (ID 0) startup scan accepted packets `>=` the TX size; with 3 bytes it would have read the receiver's 4-byte ack as a transmitter message (possibly a wrong start state). Changed to `==`. README, CLAUDE.md updated. Both sketches compile (arduino-cli, esp32 core 2.0.15, board TTGO LoRa32-OLED). Not flashed, not bench-tested.
- 2026-10-02: added "Before flashing": esptool backup/restore of both boards and a wiring check with the old firmware (Etienne's call: rule out wiring problems for the relay and the UART first).
- 2026-10-03: both boards flashed with the current firmware (RST 23, WINCH-05/06/07 struct). The esptool backup was skipped on purpose (Etienne). Fallback: rebuild the old sketches from commit `40a043e`.

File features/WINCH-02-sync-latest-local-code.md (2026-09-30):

# WINCH-02: Sync repo with latest local code

**Status:** Done
**Type:** FW
**Priority:** P0
**Safety-relevant:** Yes (the flashed code is what pilots rely on)
**Depends on:** –
**Created:** 2026-09-28 · **Last updated:** 2026-09-28

## Motivation
The repo code is about two years old (last sketch changes: `receiver.ino` 2024-04-04, `transmitter.ino` 2024-02-16, `transmitter_with-monitor-support.cpp` 2024-04-16). Etienne may have newer versions with small changes on another machine. Those may be exactly what is flashed on the winch today. All later code features must build on the code that is actually in use.

## Scope
- Collect the transmitter and receiver sketches from Etienne's other machine.
- Diff them against the repo versions (`transmitter/transmitter.ino`, `transmitter/transmitter_with-monitor-support.cpp`, `receiver/receiver.ino`, `receiver/LiPoCheck.*`).
- Determine which variant is actually flashed on the handheld and on the receiver (the OLED start screen and behaviour can help, e.g. does the transmitter try ESP-NOW?).
- Commit the newest/in-use versions as the new baseline, with a commit message listing the differences.

## Out of scope
- Cleaning up file names / PlatformIO → WINCH-03.
- Functional changes.

## Changes
- **Firmware transmitter / receiver:** replace with the in-use versions (no logic changes by Claude).

## Test plan
- [x] Diff reviewed together; every difference explained.
- [ ] Baseline compiles in the Arduino IDE (Etienne). → Deferred by Etienne (2026-09-28); to be done in WINCH-03 when the sketch folder is cleaned up.
- [ ] OLED shows `3-B: …` on the handheld (confirms ID 3 / maxPull 95 is flashed). → Deferred by Etienne (2026-09-28).

## Open questions
- [x] Where are the newer files (machine, path)? → Etienne's other machine; pasted into the session 2026-09-28.
- [x] Which transmitter variant is flashed: with or without monitor support? → Most likely with monitor support (ID 3, maxPull 95), per Etienne. Verify via OLED (`3-B: …`).
- [x] Is a VESC config backup from the actual controller available (to compare with `vesc/240601_*.xml`)? → Yes, read out on 2026-09-30: practically identical to the June 2024 backup (then changed in WINCH-17, now `vesc/260930_*.xml`; the 2024 backups are in `old/vesc-configs/`).

## Decision log
| Decision | Rationale | Date |
|---|---|---|
| Etienne's local transmitter (2025-08-24) becomes the baseline, stored as `transmitter/transmitter_with-monitor-support.cpp` | Closest repo file; most likely the flashed version. File naming is left to WINCH-03. | 2026-09-28 |
| Receiver unchanged | Local files identical to repo | 2026-09-28 |
| `receiver-pincorrected.txt` ignored | No functional difference; not relevant for now (Etienne) | 2026-09-28 |

## Findings
### Transmitter (Etienne's local `transmitter.ino`, file date 2025-08-24)
- Is the **monitor-support variant** (ESP-NOW), not the plain `transmitter.ino` from the repo.
- Code is identical to commit `8433fe0` (2024-03-21, `transmitter_with-monitor-support.cpp`) except:
  - `myID = 3` (repo: 8)
  - ⚠ `myMaxPull = 95` (repo and CLAUDE.md: 85). Resulting targets: state 2 = 17 kg, 3 = 52, 4 = 76, 5 = 95 (with 85: 15 / 46 / 68 / 85).
  - comment edits only
- It does **not** contain the later `loraConnect` changes from `a442935`/`a57a14f` (2024-04-16), which are in the repo's current `.cpp`. The ESP-NOW struct therefore differs from the repo version (no `loraConnect` field), so a monitor flashed from the repo would not match.
- ESP-NOW peer MAC `DC:DA:0C:5A:59:58` (T-Display monitor); repo `.cpp` has `DC:DA:0C:58:FE:B8`.
- LoRa structs (`LoraTxMessage`, `LoraRxMessage`) are identical to the repo, so no protocol change vs. the repo receiver.
- Etienne (2026-09-28): most likely the flashed version. `myMaxPull = 95` was chosen deliberately because it matches his take-off weight (pull ≈ pilot take-off weight). Not yet verified on the device. Quick check: the OLED's top line starts with the transmitter ID (`3-B: …` vs `8-B: …`), and the pull line shows `target/current kg` (e.g. state 2 → `17/…` with maxPull 95, `15/…` with 85).
- Existing issues in this code (same in repo, not changed, for later features):
  - `OnDataRecv` copies `setMaxPull` from the monitor into `myMaxPull` without any range check. `targetPull` is `int8_t`, so values above 127 would overflow. Relevant for WINCH-04 (monitor retirement).
  - If `esp_now_init()` or `esp_now_add_peer()` fails, `setup()` returns early, **before** the OLED and the button handlers are set up. The transmitter would then keep sending soft brake but could not be operated.

### Receiver (Etienne's local files, file date 2024-04-04)
- `receiver.ino`, `LiPoCheck.cpp`, `LiPoCheck.h`: **identical to the repo** (only whitespace / trailing blank lines differ). The repo receiver is already the local 2024-04-04 state.
- `receiver-pincorrected.txt` (second local file): despite the name, **no pin changes**. Compared by reading, not by diff: pins, structs, values, failsafe, autostop, smoothing and PPM output are the same as `receiver.ino`. The only difference is that four serial debug prints in the display block are active (`Relay On`, `Relay OFFFF`, `Line Cutter Ready`, `EMERGENCY`). Open: was a pin fix (e.g. the `RST 14` / `VESC_RX 14` collision) planned but never saved? Which of the two is flashed on the receiver?

## Log
- 2026-09-28: created
- 2026-09-28: local transmitter (2025-08-24) diffed against repo, see Findings.
- 2026-09-28: local receiver files diffed: identical to repo.
- 2026-09-28: `transmitter/transmitter_with-monitor-support.cpp` replaced with Etienne's local version. Not compiled yet.
- 2026-09-28: README.md and CLAUDE.md updated (current transmitter file, pull values for `myMaxPull = 95`). Committed. Remaining: compile in Arduino IDE, verify ID 3 on the handheld OLED.
- 2026-09-28: set to Done by Etienne. Compile and on-device check deferred (see Test plan); baseline is not compile-verified.

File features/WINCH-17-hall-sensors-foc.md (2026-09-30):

# WINCH-17: Reconnect hall & motor temperature sensors, FOC hall mode

**Status:** Bench Test
**Type:** HW / VESC (config) / Doc
**Priority:** P1
**Safety-relevant:** Yes (changes how the motor starts and brakes at low speed under load; restores motor over-temperature protection)
**Depends on:** WINCH-16
**Created:** 2026-09-29 · **Last updated:** 2026-09-30

## Motivation
Until 2026-09-30 the winch ran FOC **sensorless** (June 2024 config: `foc_sensor_mode = 0`, hall table empty), with the 6-wire sensor cable (hall sensors + motor temperature) unplugged after a VESC error (see WINCH-16). Robert's original configs used hall mode.

Sensorless FOC cannot see the rotor position at standstill and at very low speed. That is exactly where the winch does its most critical work: pre-tensioning, brake ↔ pull transitions, braking to standstill (autostop, end of rewind). With `foc_sl_erpm = 2000` and 16 pole pairs, hall mode uses the sensors below ≈125 rpm ≈ 2.8 m/s line speed. Without the sensor cable the VESC also had no motor over-temperature protection.

Background and procedure: [vesc/readme.md](../vesc/readme.md) ("Background: sensorless vs. hall sensors", "Hall sensors: how they were set up").

## Scope
1. [x] Find the cause of the VESC fault with the sensor cable connected → `FAULT_CODE_OVER_TEMP_MOTOR`, wrong temperature sensor type (see Log).
2. [x] Check the sensor cable wire by wire. Test procedure (German): [doc/qs-motor/sensors-troubleshooting.md](../doc/qs-motor/sensors-troubleshooting.md). Wire colours: [doc/qs-motor/README.md](../doc/qs-motor/README.md). Hall sensors of set 1 intact.
3. [x] Determine the motor's temperature sensor type and set `m_motor_temp_sens_type` accordingly → KTY83/122.
4. [x] Hall detection (hall detection only, not the wizard), check the hall table, set sensor mode to Hall.
5. [x] Save the XML backups → `vesc/260930_motor_config.xml`, `vesc/260930_app_config.xml`. Older backups moved to `old/vesc-configs/`.

## Out of scope
- VESC firmware changes (frozen).
- PPM input mapping / pull values (WINCH-14).
- The over-voltage fault when braking from full speed → [WINCH-22](WINCH-22-overvoltage-regen-braking.md).

## Changes
- **Hardware:** sensor cable (set 1) connected.
- **VESC:** motor config only: `m_motor_temp_sens_type` 0 (NTC 10k) → 2 (KTY83/122); hall table measured; `foc_sensor_mode` 0 (sensorless) → 2 (Hall). Everything else unchanged (checked by comparing the XML with the June 2024 backup: only these values and the automatic current/voltage offsets differ). Firmware unchanged (FW 5.3).
- **Docs:** `vesc/readme.md`, new XML backups, `doc/qs-motor/README.md`.

## Test plan
### Bench (workshop, no pilot)
- [x] Hall table: entries 1–6 valid, only 0 and 7 = 255 → `255, 65, 118, 103, 199, 34, 173, 255` (2026-09-30).
- [x] With the potentiometer: smooth start from standstill and smooth braking from slow speed (Etienne, 2026-09-30).
- [ ] Smooth start from standstill **in the pull states** (remote), also against load, no jerks or backwards twitch.
- [ ] Soft and hard brake to standstill without jerks (from low speed only until WINCH-22 is resolved).
- [ ] Motor temperature: VESC Tool showed plausible values (`T Motor` 43.6 °C after a test run, 2026-09-30). Still open: heating test (rises when warmed) and the value on the remote.
- [ ] Line length counts on the remote (WINCH-16). The VESC-internal tachometer counts.
- [ ] Sensor cable deliberately unplugged once (low pull state): VESC reaction noted here. Expected: `FAULT_CODE_OVER_TEMP_MOTOR`, no current.
- [x] Motor settings compared with the previous backup (current limits, cutoffs, temperature limits unchanged; no wizard used).

### Field (real towing)
- [ ] Several tows incl. pre-pull, step towing, release, rewind (max. state 2) and autostop: behaviour noted here.

## Open questions
- [x] Which fault code did the VESC show with the sensor cable connected? → `FAULT_CODE_OVER_TEMP_MOTOR`.
- [x] Which temperature sensor does the QS 12kW 260 V4 have? → KTY83-122 (0.97 kΩ at ~25 °C, QS manual; VESC readings plausible with the KTY83/122 setting). Heating test still open.
- [x] Which motor config is currently on the VESC? → Until 2026-09-30 practically identical to the June 2024 backup (sensorless, NTC 10k). Now: `vesc/260930_motor_config.xml` (hall mode, KTY83/122).

## Decision log
| Decision | Rationale | Date |
|---|---|---|
| Temperature sensor type KTY83/122 | Measured 0.97 kΩ at ~25 °C, QS manual; NTC setting caused a permanent over-temperature fault | 2026-09-30 |
| Hall detection only, not the Setup Motor FOC wizard | The wizard would also reset current limits, battery and temperature settings | 2026-09-30 |
| FOC hall mode | Smooth start/braking at standstill and low speed under load | 2026-09-30 |

## Log
- 2026-09-29: created. Background, recommendation and procedure written in vesc/readme.md.
- 2026-09-29: sensor test procedure added as doc/motor-sensors-troubleshooting.md (German, at Etienne's request).
- 2026-09-30: motor docs moved to doc/qs-motor/ (sensor test procedure now doc/qs-motor/sensors-troubleshooting.md, new motor data sheet doc/qs-motor/README.md).
- 2026-09-30 (Etienne): temperature sensor (sensor set 1) measured 0.97 kΩ at ~25 °C, matches KTY83-122. Not yet heated to confirm the rising resistance.
- 2026-09-30 (Etienne): all three hall sensors of sensor set 1 (own plug) checked by measurement: intact. Wire colour mapping motor ↔ plug recorded in doc/qs-motor/README.md (plug colours differ from motor colours). Sensor set 2 (original QS plug) never connected, unchecked.
- 2026-09-30 (VESC Tool 3.01 session with Etienne, FW 5.3 confirmed):
  - Sensor cable connected → red LED; `faults`: `FAULT_CODE_OVER_TEMP_MOTOR`. Cause: `m_motor_temp_sens_type = 0` (NTC 10k); the KTY83's ~1 kΩ reads as ~100 °C, above the 75/85 °C limits → no current, the motor didn't turn even with the potentiometer.
  - Backups taken, sensor type set to KTY83/122 (Motor Settings → General → Advanced), written. Motor first jittered with the potentiometer; after a VESC restart no faults and the potentiometer worked normally (sensorless).
  - Test at full speed with the potentiometer, then fast braking → `FAULT_CODE_OVER_VOLTAGE` (fault at 72.1 V, Realtime Data showed up to 88 V) → [WINCH-22](WINCH-22-overvoltage-regen-braking.md).
  - Hall detection run (Hall Sensors tab only): table `255, 65, 118, 103, 199, 34, 173, 255`. Sensor mode set to Hall, written. Potentiometer test: smooth start and smooth braking from slow speed.
  - New backups `vesc/260930_motor_config.xml` / `vesc/260930_app_config.xml`; old backups moved to `old/vesc-configs/`. Status → Bench Test.

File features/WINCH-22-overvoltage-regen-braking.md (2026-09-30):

# WINCH-22: Over-voltage fault when braking (regenerative braking)

**Status:** Planned
**Type:** HW / VESC (read-only) / Doc
**Priority:** P0
**Safety-relevant:** Yes (all brakes of the winch are regenerative: soft brake, hard brake, autostop. If the VESC shuts down with an over-voltage fault while braking, it stops braking and the drum runs free.)
**Depends on:** –
**Created:** 2026-09-30 · **Last updated:** 2026-09-30

## Motivation
On 2026-09-30 (VESC Tool session, WINCH-17) Etienne turned the potentiometer slowly to full (motor at maximum speed, duty 95 %, drum without line load), then turned it back down quickly. The VESC braked the motor (motor current down to about −60 A) and then reported **`FAULT_CODE_OVER_VOLTAGE`**:
- `faults`: fault at **72.11 V** (= `l_max_vin` 72 V).
- Realtime Data afterwards showed **Volts In 88.0 V** (the controller is rated for spikes up to 75 V).
- At standstill afterwards: 63.1 V (normal). No fault after a restart.

The remote was on, in state −1 (soft brake). In potentiometer mode the VESC ignores the PPM input; when the potentiometer goes back below 0.5 V, normal PPM operation (soft brake from the remote) and the braking take over.

## Suspected cause (not verified)
The braking energy could not flow back into the battery fast enough, so the DC bus voltage rose. Candidates:
- **Daly BMS** (installed August '26): charge path blocked or limited when regen current flows (charge MOSFET off, charge over-current protection, charge current limit). Etienne: charge and discharge can be enabled separately; the VESC and the charger use the same port (common port).
- Before the BMS (balancer only), regen went straight into the cells. Unknown whether over-voltage faults happened before.
- Battery internal resistance and wiring: at about 60 A a rise of only a few volts is expected, not 9+ V, so this alone is unlikely.
- Fast brake transient (VESC ramp settings, battery current limit `l_in_current_min = −290 A`).

## Scope (diagnosis first)
- [ ] Daly app: charge MOSFET state, charge over-current limit / protection settings, alarm/event log at the time of the test.
- [ ] Reproduce carefully at **low** speed first, then step by step higher, with VESC Tool Realtime Data (Volts In, I Batt) recording; stop at the first voltage rise above ~70 V.
- [ ] Check whether the same happens with the remote (hard brake from a pull state at moderate speed, winch on the stand, no pilot).
- [ ] Decide the fix (BMS settings, VESC battery regen current limit `l_in_current_min`, max input voltage, ...). Any VESC config change needs Etienne's decision and a bench test.

## Until resolved
- Don't brake from high drum speed; potentiometer only with little travel (it has no speed limit).
- Towing: the rewind rule (max. state 2) keeps speeds low. Braking from a pull state at speed is exactly the risky case.

## Out of scope
- VESC firmware changes (frozen).

## Test plan
### Bench (workshop, no pilot)
- [ ] Brake from increasing speeds (potentiometer and remote hard brake): Volts In stays below 70 V, no fault.
- [ ] Autostop brake (18 A) from rewind speed: no fault.

### Field (real towing)
- [ ] Normal tow session with brake manoeuvres: no over-voltage fault (`faults` checked afterwards).

## Open questions
- [ ] Did over-voltage faults happen before the BMS was installed?
- [ ] Daly BMS: charge current limit and protection settings?
- [ ] Was the 88 V a real voltage on the DC bus or a measurement artefact after the fault?

## Decision log
| Decision | Rationale | Date |
|---|---|---|
| BMS analysis postponed, hall setup first (Etienne) | Hall detection runs at low speed and low current, no high-speed braking | 2026-09-30 |

## Log
- 2026-09-30: created after the over-voltage fault in the VESC Tool session (WINCH-17).

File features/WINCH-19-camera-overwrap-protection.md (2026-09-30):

# WINCH-19: Winch camera & line overwrap protection

**Status:** In Progress
**Type:** HW
**Priority:** P1
**Safety-relevant:** Yes (a line wrap at the drum destroys the line and the winding gear and can end a tow abruptly; the camera is powered from the VESC's 5 V output)
**Depends on:** –
**Created:** 2026-09-30 · **Last updated:** 2026-09-30

## Motivation
When towing alone, the pilot is far away from the winch at launch and cannot see whether the line lies properly on the drum. Once the line was pulled out in neutral (state 0): when Etienne stopped after walking faster, the drum overran and unwound loose turns right at the drum. On launch this caused a line wrap that destroyed the line and the 3D-printed gear of the winding mechanism. (The gears have since been replaced by laser-sintered steel gears.)

The usage rule "pull the line out with soft brake only" is now in the README (2026-09-30). This feature adds two hardware measures on top of it.

## Scope
1. **Camera at the winch**
   - View of the drum and the line guide (barrel-cam winding / azimuth system).
   - Live image on a portable monitor carried to the launch site: check before launch that the line lies properly on the drum.
   - Record the tow at the winch to document it (and analyse incidents).
2. **Overwrap protection**
   - Mechanical guard that keeps loose line from jumping over the drum flange or wrapping around the axle/gear, e.g. a close-fitting guard or line holder over the drum.
   - Must not hinder normal winding and must not add friction to the line.
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

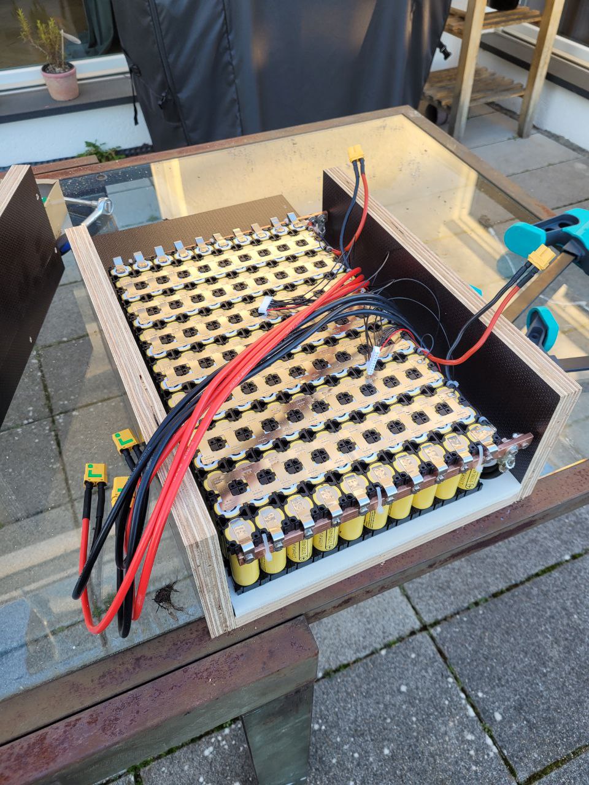
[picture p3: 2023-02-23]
doc/battery.jpeg

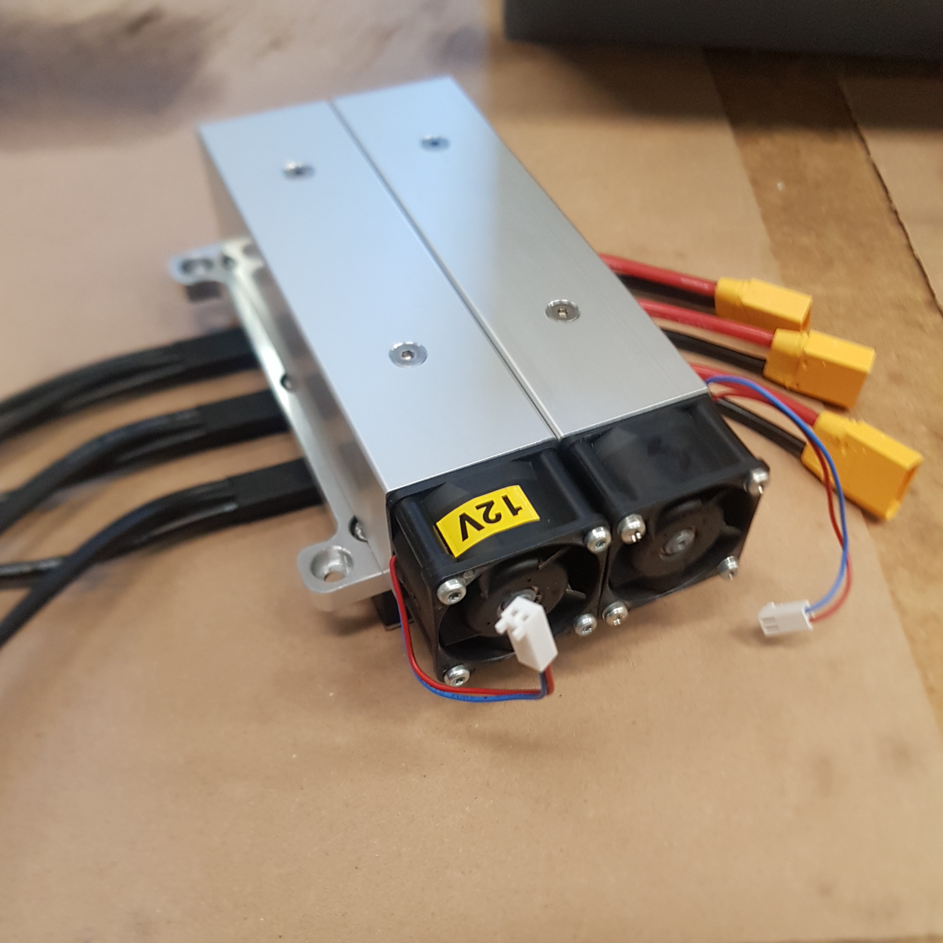
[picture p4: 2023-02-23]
doc/VESC_cooler.jpg

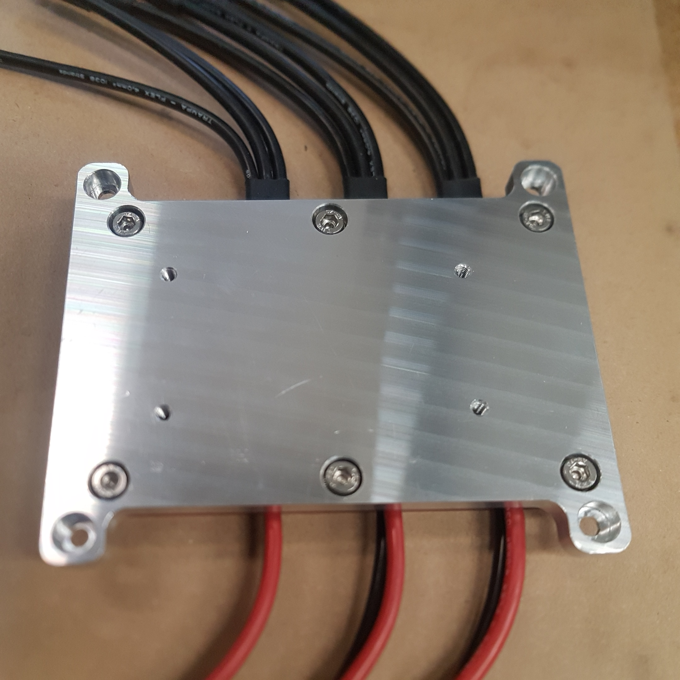
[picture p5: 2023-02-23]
doc/VESC_cooler_connectionplate.jpg

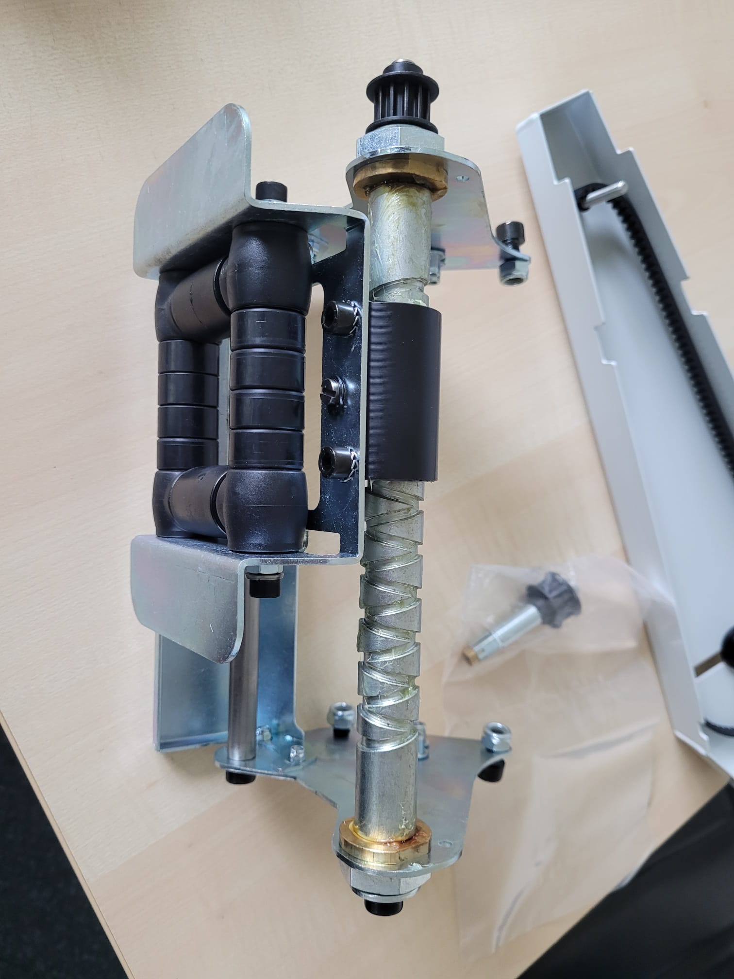
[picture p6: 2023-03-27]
doc/winding_mechanism.jpeg

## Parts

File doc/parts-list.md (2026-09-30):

# Parts Lists and sourcing links

This is a list of parts including sourcing links 

# Motor

* Motor - QS Motor, 12kW 260 V4 https://www.aliexpress.com/item/4001237537247.html Version 72V 100kph. Motor data, sensor wiring and manuals: [qs-motor/README.md](qs-motor/README.md)

# Controller #
* Controller - VESC 75/300 https://trampaboards.com/vesc-75v-300a-black-anodised-non-conductive-cnc-housing--the-most-powerful-vedder-electronic-speed-controller-ever-p-26284.html
* Cooler for VESC https://www.reichelt.de/miniatur-luefteraggregat-12-volt-dc-lam-4150-12v-p75427.html
* Some JST PHR 2.0mm pin pitch Connectors for connecting with the COMM and PPM Port Connectors on the VESC 75/300

# Cables / Connections
* 3x Anderson Type Connector for connecting Motor & Controller, 120A https://www.amazon.de/gp/product/B08MTKHMJD/
* 2x 6 AWG (13,3mm²) 70cm cable for connecting controller to motor https://www.amazon.de/gp/product/B091KLY921

# Remote / Receiver
* Transmitter / Receiver - 3x LILYGO® TTGO ESP32-Paxcounter LoRa32 V2.1 1.6 Version 915MHZ LoRa ESP-32 OLED http://www.lilygo.cn/prod_view.aspx?TypeId=50060&Id=1271&FId=t3:50060:3
* 868 MHz LoRa 6dBi Fiberglas Antenna (N-Stecker) for the receiver https://www.amazon.de/gp/product/B09MD895ZR

# Camera / video link (WINCH-19)
* Camera + video transmitter on the winch - BetaFPV P1 Air Unit HD, 5 V (rotorama), powered from the VESC 5 V output
* Video receiver - HGLRC Draco VRX Ground Unit, DC 7-36 V (2S-6S), records to SD card (rotorama)
* Monitor - Elecrow 5 inch HDMI monitor, 5 V via USB-C (Amazon)
* LiPo 3S 11.1 V 5200 mAh for receiver and monitor (mobile, in the cockpit pocket)
* DC-DC converter LiPo → 5 V for the monitor
* 3D-printed housings for camera and receiver/monitor unit

# Battery
* Battery - 2x 8S10P built with samsung inr21700-40t 4000mah 35A - connected in series to result in 16S10P = 57,6V. The reason is 8s can be charged with common RC chargers.
* 10 AWG Silicone Cable going to the VESC Controller, 3x pairs of cable with 3x XT90 Connectors
* ~~16S Balancer Board https://de.aliexpress.com/item/1005004553750067.html~~ (no longer used: replaced by the Daly BMS below with active balancing, August '26)
* BMS - Daly Smart BMS, version R24TS, 7-17 cells (7S-17S), 300A, with active balancing. Added in August '26
* 1x2 Plastic Battery Holder for 21700 LiIon Cells https://de.aliexpress.com/item/1005004377607379.html (160 pieces for 160 Cells - 8S16P)
* 2P 0,15 Nickel Strip
* Mini Spot Welder

# Charger
* 12 AWG (5,26mm²) Silicone Cable on the charging side,  XT60 connectors
* 8S JST-XH Balancer Cable https://www.amazon.de/gp/product/B08JV9QWTK (two cables are connected to 8 Batteries in series each)
* Power Supply for Charger: 2 Pieces 24V 50A 1200W Schalternetzteil 230V AC https://www.amazon.de/dp/B077CP69P6
* Charger - 2 Pieces ISDT AIR8 500W 20A Lipo Akku Balance Ladegerät Smart Digital Ladegerät für RC 1-8S Akku Batterien - https://www.amazon.de/ISDT-Touchscreen-Balance-Ladeger%C3%A4t-Batterien/dp/B081YZLMV4/ Connects to power supply and battery via XT90, Balancer Cable connects to battery via 

# Frame

## Winding Mechanism
* I am using a barrel cam mechanism, following this principle: https://www.youtube.com/shorts/LLIwVdaRViM - I used this part (with modifications): https://www.ebinger-gmbh.com/aufroller/zubehoer-aufrolltechnik/automatische-schlauchf%C3%BChrung-1-2-5-8-1-610-010.html - Artikel-Nr (SKU).: 1.610.010
* Gears of the winding mechanism: **laser-sintered steel**. They were first 3D-printed in plastic to check function and fit; a plastic gear was destroyed in a line wrap, the steel gears are for permanent use. Source / drawings: *to be completed* (Fusion + STL files, see [WINCH-21](../features/WINCH-21-gear-cad-files.md))

## Azimuth System
* Steel Pipe E235, 20x4mm (20mm outer diameter, 4mm wall thickness = 12mm inner diameter) https://www.ebay.de/itm/112957195210
* 2x Flanged Bearing (Flanschlager) UCFL (2 holes, oval), Wellen Ø 20mm (UC204) https://www.ebay.de/itm/362712761631
* Cable Pulley (Seilrolle) Ø 59mm, Nabe Ø 10mm, Thickness 15mm, for 6mm rope, zinc-plated https://e-rader.de/mit-kugellager/1850-cm446l-profil-rollen-fuer-seil-mit-kugellager-.html
* 2x Pipe Roller ( Tragrolle )

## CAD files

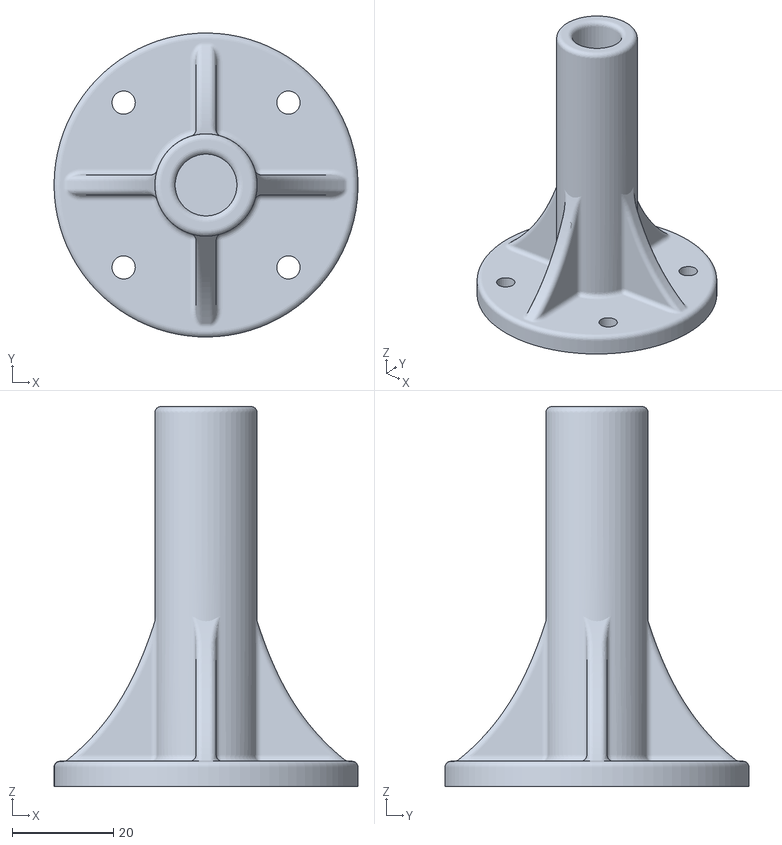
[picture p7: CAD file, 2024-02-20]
doc/Carbon-Stab-Halterung.stl
60.0 x 60.0 x 75.0

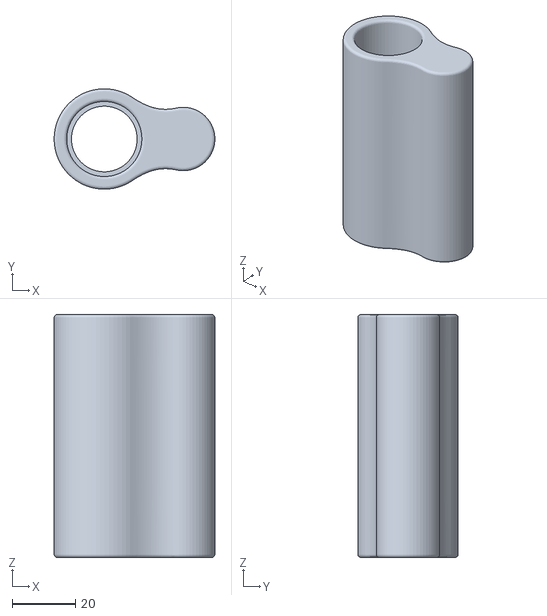
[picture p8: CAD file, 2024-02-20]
doc/Antenne-Carbon-Stabhalterung.stl
50.9 x 31.8 x 77.0

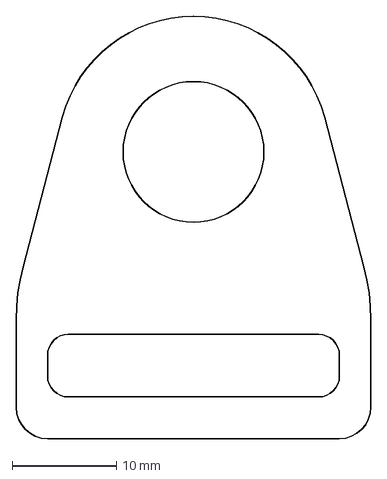
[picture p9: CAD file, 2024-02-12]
doc/hering-spanngurt.dxf
34.0 x 40.5 mm

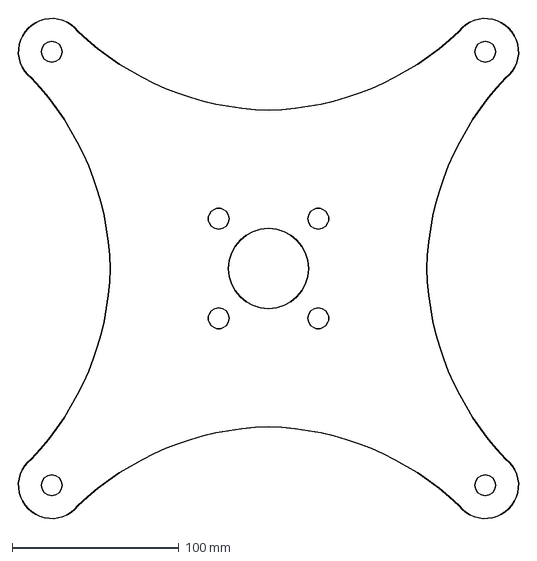
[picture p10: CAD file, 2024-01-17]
doc/bodenplatte.dxf
302.4 x 302.4 mm

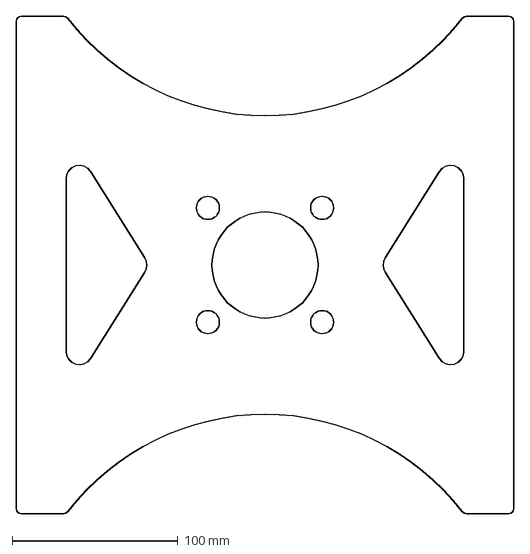
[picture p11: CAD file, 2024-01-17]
doc/windenhalterung.dxf
300.0 x 300.0 mm

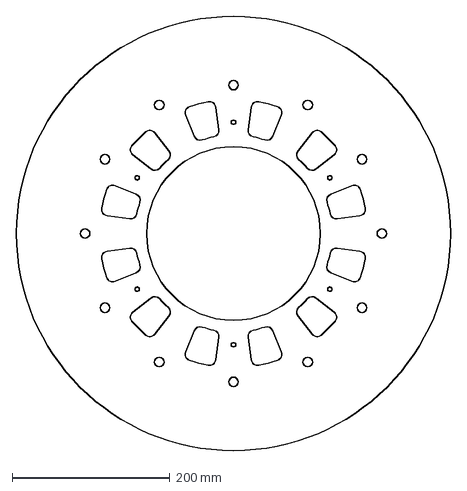
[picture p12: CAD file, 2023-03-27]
doc/230326_trommelscheibe.dxf
550.0 x 550.0 mm

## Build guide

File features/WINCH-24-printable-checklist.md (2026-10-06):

# WINCH-24: Printable checklist (packing, setup, before launch)

**Status:** Planned
**Type:** Doc
**Priority:** P1
**Safety-relevant:** Yes (a forgotten step, e.g. potentiometer not at the "off" end or line pulled out in neutral, has already caused damage)
**Depends on:** –
**Created:** 2026-09-30 · **Last updated:** 2026-10-06

## Motivation
Etienne wants a short checklist to print, laminate and stick onto the winch: what to pack before leaving, how to set up the winch, what to check before pulling out the line and before launch. Several incidents came from single forgotten or wrong steps (line pulled out in neutral → line wrap; rewind with too much pull → azimuth system destroyed). A checklist on the winch makes the order repeatable, also for other pilots or helpers.

## Scope
- One printable page per phase, or one page front/back, readable outdoors: large font, checkboxes, no explanations (details stay in the README / manual).
- Source as Markdown in `doc/` (e.g. `doc/checklist.md`) plus a print-ready PDF.
- Phases:
  0. **Day before** (ideally): charge batteries
  1. **Packing** (before leaving home)
  2. **Setup** (on site)
  3. **Before pulling out the line**
  4. **Before launch**
  5. **After the tow / packing up** (optional, to be decided)
- Link from README usage section and WINCH-09 (manual).

## Draft content (from Etienne, 2026-09-30; to be completed and ordered)

**0. Day before (ideally)**
- [ ] 11 V LiPo for the camera receiver + monitor (cockpit) charged
- [ ] Vario charged
- [ ] 60 V winch battery charged
- [ ] Cordless screwdriver battery charged
- [ ] Winch remote(s) charged

**1. Packing**
- [ ] Winch
- [ ] Line parachute (drogue)
- [ ] Winch battery
- [ ] Controller (VESC) / receiver unit
- [ ] Remote(s); admin remote (red) if towing with several pilots
- [ ] Ratchet straps, ground screws and cordless screwdriver (to fix the winch to the ground)
- [ ] Antenna (receiver)
- [ ] Camera (winch, powered by the VESC), camera receiver + monitor (cockpit), 11 V LiPo for receiver/monitor
- [ ] Paraglider, harness with reserve, cockpit

**2. Setup**
- [ ] Fix the winch to the ground with ratchet straps (and screws)
- [ ] Set up and connect the antenna
- [ ] Switch on controller (VESC) and receiver
- [ ] VESC LED not red (otherwise read faults, see vesc/vesc-tool-guide.md)
- [ ] **Potentiometer fully left (off end)**
- [ ] Switch on the remote, link OK (RSSI on the OLED), winch mode **soft brake "B -1" (−7 kg)**
- [ ] Camera and monitor on, image of the drum visible

**3. Before pulling out the line**
- [ ] **Soft brake active (B -1), never neutral** (neutral → drum overruns → line wrap)
- [ ] Pull out the line with the drogue, walk steadily

**4. Before launch**
- [ ] Line lies properly on the drum (monitor)
- [ ] Line, weak link, connection to the harness checked
- [ ] Remote in hand / fixed, OLED shows the link
- [ ] Potentiometer still at the off end

**5. After the tow** (to be decided)
- [ ] Rewind with **max. state 2 (prePull)**
- [ ] Remote stays **on** until the line is fully in and AutoStop has stopped the drum
- [ ] ...

## Candidates to add (to be decided with Etienne)
- Sensor cable (hall + motor temperature) plugged in: without it the VESC reports over-temperature and gives no current.
- Remote OLED plausible: battery %, motor temperature.
- Wind / weather / airspace, helper briefed (if any).
- Several pilots: each pilot's own remote (own ID and max pull), admin remote rules (README "Several pilots / several remotes").

## Out of scope
- Detailed explanations (README, WINCH-09 manual, vesc/vesc-tool-guide.md).

## Changes
- **Docs:** `doc/checklist.md` + PDF, links from README and WINCH-09.

## Test plan
- [ ] Printed and laminated, used on site once; missing or wrong items corrected.

## Open questions
- [ ] Format: A5 or A4? One sheet front/back or one sheet per phase?
- [ ] Language on the printout: German or English? (Repo docs are English; a German printout for use on site is possible.)
- [ ] Order of setup steps as Etienne actually does them (e.g. camera before or after the remote)?
- [x] Is the 11 V monitor battery the same as the "LiPo for receiver/monitor", and does the winch camera need its own battery? → Same battery; the winch camera has no battery, it is powered by the VESC (Etienne, 2026-10-06).

## Log
- 2026-09-30: created (Etienne). Draft content from Etienne's list; candidates from today's findings added.
- 2026-10-06: new phase "0. Day before (ideally)" with the charging items from Etienne (11 V monitor battery, vario, 60 V winch battery, screwdriver battery, remote(s)). The old "All batteries charged" line in Packing was folded into it.

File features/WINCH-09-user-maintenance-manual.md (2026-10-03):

# WINCH-09: User & maintenance manual

**Status:** Planned
**Type:** Doc
**Priority:** P1
**Safety-relevant:** Yes (operating procedures)
**Depends on:** WINCH-01, WINCH-08
**Created:** 2026-09-28 · **Last updated:** 2026-09-28

## Motivation
Several seasons of towing experience exist only in Etienne's head. A written manual makes operation repeatable and safer for Etienne, winch operators and other builders. The README usage section is short and partly outdated.

## Scope
New `doc/manual.md`, linked from the README. Content gathered in interview sessions with Etienne:
1. **Transport & setup:** trailer, anchoring (ground stakes / straps), line layout, azimuth system alignment.
2. **Pre-flight checklist:** battery charge, remote batteries, LoRa link check, poti at off end, line & weak link, brake test.
3. **Towing procedure:** state sequence (default → pre → take-off → full), step towing, communication, what to do on link loss (failsafe behaviour).
4. **Release & rewind:** ⚠ max. state 2, autostop, what to do if the line lands on the ground.
5. **After the session / packing.**
6. **Battery:** charging (2× ISDT AIR8, 8S packs), storage voltage, balancing, long-term storage.
7. **Maintenance intervals:** line (Dyneema) inspection/replacement, weak link, bearings & pulleys of the azimuth system, barrel-cam winding, connectors (XT90, Anderson), VESC cooling, cable strain relief, remote.
8. **Troubleshooting:** known failure modes and fixes.
9. **Incident log:** what went wrong and what was learned (e.g. the rewind incident; the line wrap after pulling the line out in neutral, which destroyed the line and the 3D-printed gear: pull out with soft brake only, see README).
10. **Several pilots / admin remote:** one remote per pilot (own ID and max pull), red admin remote (ID 0), takeover rules (see README "Several pilots / several remotes").

## Out of scope
- Build instructions (the repo is explicitly not a build guide).

## Changes
- **Docs:** new `doc/manual.md`, README link, and slimming down the README usage section to a pointer.

## Collected content: incident log
Collected here until `doc/manual.md` exists.

| Incident | Cause | Consequence | Lesson / measure |
|---|---|---|---|
| Carabiner pulled into the azimuth system | Line rewound with too much pull after release (old README said fullPull) | Azimuth system destroyed / line snapped, whole winch rebuilt | Rewind with max. state 2 only (WINCH-01, README) |
| Line fell onto the towing track after release | Remote switched off right after release, before the line was fully rewound and AutoStop had stopped the drum. The receiver does not know about AutoStop: its failsafe kept defaultPull for 20 s, then soft brake | Rest of the line lay on the towing track; rewound afterwards with the potentiometer (README E) | Keep the remote on (state 1 or 2) until AutoStop has stopped the drum, only then switch it off (README C, 2026-10-02); checklist item (WINCH-24) |
| Line wrap at the drum on launch | Line pulled out in neutral (state 0) while towing alone; the drum overran when Etienne stopped walking and loose turns formed at the drum | Line and the 3D-printed plastic gear of the winding mechanism destroyed | Pull the line out with soft brake only (README, 2026-09-30); camera + overwrap protection (WINCH-19) |

**Good practice (lesson learned):** the gears of the winding mechanism were first 3D-printed in plastic to check function and fit. They have since been replaced by **laser-sintered steel gears** for permanent use. Etienne's verdict: a good decision. Recommended approach for custom parts: prototype in printed plastic, then switch to a durable material (e.g. laser-sintered steel) for the part in use. Date of the replacement: *to be completed*.

## Test plan
- [ ] Etienne reviews each chapter.
- [ ] Checklists are used in the field once and refined.

## Open questions
- [x] Is a printable one-page checklist (PDF) wanted as well? → Yes, laminated on the winch: [WINCH-24](WINCH-24-printable-checklist.md).
- [ ] Is there DHV-relevant documentation to reference?

## Decision log
| Decision | Rationale | Date |
|---|---|---|

## Log
- 2026-09-28: created
- 2026-09-30: incident log started (rewind incident, line wrap after pulling out in neutral); lesson learned: printed plastic gears for prototyping, laser-sintered steel gears for use (Etienne). Several pilots / admin remote added to the scope.
- 2026-10-02: incident added: remote switched off too early after release, line fell onto the towing track (Etienne). README release section has a new warning.

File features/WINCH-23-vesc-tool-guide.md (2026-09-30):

# WINCH-23: VESC Tool user guide

**Status:** In Progress
**Type:** Doc
**Priority:** P1
**Safety-relevant:** No (documentation; describes safety-relevant settings but changes nothing)
**Depends on:** WINCH-17
**Created:** 2026-09-30 · **Last updated:** 2026-09-30

## Motivation
Etienne wants to understand how to work with VESC Tool (desktop and smartphone) and be able to look everything up again months later: reading faults, realtime data, reading/writing settings, backups, the temperature sensor setting, hall detection, ERPM and the speed ranges of hall / sensorless / HFI. Based on the VESC Tool session of 2026-09-30.

## Scope
- [x] `vesc/vesc-tool-guide.md` (desktop VESC Tool 3.01, FW 5.3), referencing the current configs `vesc/260930_*.xml`.
- [ ] Smartphone app section (version, connection, available functions).
- [ ] Etienne reviews the guide against VESC Tool (menu names and button positions in 3.01).

## Out of scope
- Changing VESC settings.

## Changes
- **Docs:** new `vesc/vesc-tool-guide.md`; links from `vesc/readme.md`, README.md, CLAUDE.md. Tachometer / line-length hypothesis added to WINCH-08 and CLAUDE.md.

## Open questions
- [ ] Smartphone app: version, FW 5.3 compatibility, connection (Bluetooth module? USB-OTG?).
- [ ] Is the "Rotor Position" check in section 5 useful in practice?

## Log
- 2026-09-30: created. Guide written from today's session: connecting, read/write, backups, terminal and fault codes, realtime data, temperature sensor type, ERPM table and hall / sensorless / HFI ranges, tachometer, hall detection, don'ts, worked example. While calculating the ERPM table: hypothesis that the ~0.7× line length and the autostop distance come from the drum size (see WINCH-08).

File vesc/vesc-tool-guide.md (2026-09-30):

# VESC Tool guide for this winch

How to connect to the winch's VESC, read faults, use the realtime data, change settings and redo the hall sensor setup. Written so it can be followed again months later. Everything refers to the current configuration of this winch:

- Motor config: [260930_motor_config.xml](260930_motor_config.xml)
- App config: [260930_app_config.xml](260930_app_config.xml)

Background (what the settings mean, why hall mode, autostop): [readme.md](readme.md). Motor data and sensor wiring: [doc/qs-motor/README.md](../doc/qs-motor/README.md).

> ⚠ **Safety first.** Whenever the motor can turn (detection, potentiometer, test buttons in VESC Tool): winch secured, **line without load, nobody at the drum**. Don't brake from high speed until [WINCH-22](../features/WINCH-22-overvoltage-regen-braking.md) (over-voltage when braking) is resolved.

## 1. Versions: don't update

| Part | Version | Note |
|---|---|---|
| VESC firmware | **5.3** with the autostop patch | Confirmed 2026-09-30. Hardware `75_300_R3`. |
| VESC Tool (desktop) | **3.01** | Matches FW 5.3. |
| VESC Tool (smartphone) | *to be completed* | See section 11. |

- **Never accept a firmware update** offered by VESC Tool. It would replace the patched firmware with a stock firmware **without line autostop**.
- A newer VESC Tool may not work properly with FW 5.3 or may push you to update the firmware. Stay on 3.01 for this winch.

## 2. Connecting

1. Winch battery on, VESC on (power switch), LED blue, then dim green = firmware running.
2. USB cable (Mini-USB on this controller) to the laptop.
3. VESC Tool → **Connection** (left menu) → select the serial port (e.g. COM3) → **Connect** (or "Autoconnect" on the welcome page).
4. Bottom right should show "Connected (serial) to COM…". Left, under **CAN-Devices**: `VESC 75 300 R3 local`.
5. **Firmware** page (left menu) shows firmware and hardware version: `Fw: 5.3, Hw: 75_300_R3`. Check it once per session.

## 3. Reading and writing settings (the most important rule)

On the right edge of VESC Tool there is a column of buttons for the **motor** configuration (M) and the **app** configuration (A):

| Button (go by the tooltip) | What it does |
|---|---|
| **Read** configuration | Loads the settings **from the VESC** into VESC Tool. |
| **Read default** configuration | Loads **factory defaults** into VESC Tool. ⚠ Never write these to the winch. |
| **Write** configuration | Sends the settings in VESC Tool **to the VESC**. In VESC Tool 3.01 this is the icon with the arrow pointing **down**. |

Rules:
1. **Always read first**, then change, then write. VESC Tool does not load the VESC's settings by itself; without reading you edit (and write) whatever happens to be in VESC Tool.
2. A change in VESC Tool does **nothing** until it is written.
3. Motor settings and app settings are written separately (M and A).
4. After writing: read again and check the value really changed.

### Backups (XML)
- Before and after every change: **read**, then **File → Save Motor Configuration XML as…** and **File → Save App Configuration XML as…**
- Name: date prefix, e.g. `260930_motor_config.xml`. Use a new name so the "before" state is not overwritten.
- Commit the new backups to `vesc/`, move superseded ones to `old/vesc-configs/`.
- **Never load an old or foreign XML and write it to the winch** (it contains motor measurements, hall table and limits of another state or motor).

## 4. Terminal: reading faults

Left menu → **VESC Dev Tools** (or the Terminal menu at the top) → **Terminal**. Type a command, press Enter.

| Command | What it shows |
|---|---|
| `faults` | All faults since the VESC was switched on, with a snapshot of the values at that moment. "No faults registered" if there were none. The list is cleared by a restart. |
| `help` | List of all terminal commands of this firmware. |

Example from 2026-09-30 (sensor cable connected, wrong temperature sensor type):

```
Fault            : FAULT_CODE_OVER_TEMP_MOTOR
Current          : -0.7         motor current at the moment of the fault (A)
Voltage          : 63.45        battery voltage (V)
Duty             : -0.000
RPM              : 0.1          electrical RPM (ERPM), see section 7
Tacho            : 4            tachometer counts, see section 8
Temperature      : 27.66        MOSFET (controller) temperature, not motor temperature
```

### Fault codes that matter on the winch

| Fault | Meaning | What to check on this winch |
|---|---|---|
| `FAULT_CODE_OVER_TEMP_MOTOR` | Motor temperature above `l_temp_motor_end` (85 °C) → no current. | Motor really hot? Otherwise: **sensor cable unplugged** or **wrong sensor type** (must be KTY83/122, section 6). Happened 2026-09-30 with the NTC setting. |
| `FAULT_CODE_OVER_TEMP_FET` | Controller above 100 °C. | Cooling fan running? Airflow in the enclosure? |
| `FAULT_CODE_OVER_VOLTAGE` | Battery voltage above `l_max_vin` (72 V). | Happens when **braking** feeds energy back and the battery doesn't take it. Happened 2026-09-30 when braking from full speed (fault at 72.1 V) → [WINCH-22](../features/WINCH-22-overvoltage-regen-braking.md). |
| `FAULT_CODE_UNDER_VOLTAGE` | Battery voltage below `l_min_vin` (12 V). | Battery empty, BMS switched off, loose connector. |
| `FAULT_CODE_ABS_OVER_CURRENT` | Current above `l_abs_current_max` (290 A). | Very hard pull/brake, wrong motor measurement, wiring fault. |
| `FAULT_CODE_DRV` | Gate driver fault (power stage). | Serious: stop, check phase wires, contact Trampa. |

The **red LED** on the VESC means a fault is active. Always read `faults` before the next tow.

## 5. Realtime data

Left menu → **Data Analysis → Realtime Data**. Start the stream with the **"Stream realtime data"** button (right edge, "RT"). Tabs: Current, Temperature, RPM, FOC, Rotor Position, Experiment.

The **Current** tab plots three lines:

| Line | Meaning |
|---|---|
| Current in (battery current, I Batt) | Current from the battery (positive) or back into it (negative = braking with energy recovery). |
| Current motor (I Motor) | Current in the motor windings. **This is the pull (torque):** ≈ 3.4–3.6 A per kg of line pull. Negative = braking. |
| Duty cycle | How much of the battery voltage the VESC puts on the motor (0–95 %). Roughly proportional to speed. At 95 % the motor can't go faster. |

At low speed the motor current can be much higher than the battery current (the VESC works like a gearbox for current). That is normal.

Values below the plot:

| Field | Meaning | Normal on the winch |
|---|---|---|
| Power | Battery power (W), negative when braking | |
| Duty | Duty cycle in % | 0 at standstill |
| ERPM | Electrical RPM (section 7) | 0 at standstill |
| I Batt / I Motor | See above | |
| T FET | Controller temperature | Ambient to ~60 °C; limits 85/100 °C |
| T Motor | Motor temperature (KTY83 sensor) | Cold motor ≈ ambient. Limits 75/85 °C |
| Fault | Current fault, `NONE` if OK | `NONE` |
| Tac / Tac ABS | Tachometer counts (section 8). Tac counts up and down, Tac ABS only up | |
| Ah / Wh Draw / Charge | Energy drawn / recovered since power-on | |
| Volts In | Battery voltage | 48–67.2 V. **Above 72 V = over-voltage fault** |

**Temperature** tab: T FET and T Motor over time. Useful for the heating test of the motor sensor (warm the motor with a hair dryer, T Motor must rise).

**Rotor Position** tab: with hall mode, you can turn the drum slowly by hand and watch the position change smoothly (no jumps). Useful after the hall detection.

### ⚠ The control bar at the bottom
The bottom bar has fields and play buttons for **D** (duty), **ω** (speed), **IB / I** (current), **P** (position), **HB** (handbrake) and a red **STOP** button. The play buttons **drive the motor directly** from the laptop, bypassing the remote. Don't use them on the winch unless the winch is secured and nobody is near the drum. **STOP** releases the motor.

## 6. Changing the motor temperature sensor type

This winch's motor has a **KTY83-122** temperature sensor (0.97 kΩ at ~25 °C, see [doc/qs-motor/README.md](../doc/qs-motor/README.md)).

1. **Read** motor configuration.
2. **Motor Settings → General → tab "Advanced" → Motor Temperature Sensor Type = KTY83/122.** (Not in the "Temperature" tab; that one only has the limits.)
3. Leave the limits in the Temperature tab unchanged: Motor Temp Cutoff Start **75 °C**, End **85 °C**.
4. **Write** motor configuration, then check T Motor in Realtime Data (≈ ambient when cold).

In [260930_motor_config.xml](260930_motor_config.xml): `m_motor_temp_sens_type = 2` (KTY83/122). Until 2026-09-30 it was `0` (NTC 10k): the KTY83's ~1 kΩ then reads as ~100 °C → `FAULT_CODE_OVER_TEMP_MOTOR`, red LED, no current.

With KTY83/122, an **unplugged sensor cable reads as extremely hot** → same fault. The sensor cable must always be connected.

Also in the Advanced tab: **Auxiliary Output Mode** = "Temp motor or mosfet > 50 C" (`m_out_aux_mode = 11`): the VESC's switched AUX output turns on above 50 °C.

## 7. ERPM, speed ranges, hall sensors and HFI

### What ERPM is
VESC Tool shows speed as **ERPM** (electrical revolutions per minute). The motor has 32 magnets = **16 pole pairs**, so one turn of the drum is 16 electrical revolutions:

- **drum rpm = ERPM ÷ 16**
- **line speed (m/s) = drum rpm × drum circumference ÷ 60**. Empty drum: diameter 0.43 m (`si_wheel_diameter`), circumference π × 0.43 ≈ 1.35 m. With line wound on, the effective diameter is larger, so the real line speed is somewhat higher.

| ERPM | Drum rpm | Line speed (empty drum) | Meaning in the config |
|-----:|---:|---|---|
| 150 | 9 | 0.2 m/s (0.8 km/h) | `foc_openloop_rpm` (only used in sensorless mode) |
| 500 | 31 | 0.7 m/s (2.5 km/h) | `foc_hall_interp_erpm`: hall interpolation starts |
| 2000 | 125 | 2.8 m/s (10 km/h) | `foc_sl_erpm`: switch from hall sensors to sensorless observer |
| 4300 | 269 | 6.1 m/s (22 km/h) | example from the realtime data on 2026-09-30 |
| ≈ 12 600 | ≈ 790 | ≈ 18 m/s (64 km/h) | rough theoretical maximum at 63 V and 95 % duty without load (calculated from the flux linkage, not measured) |

### How the VESC knows the rotor position in hall mode (`foc_sensor_mode = 2`)

| Speed | Position from | How |
|---|---|-----|
| **0 – 500 ERPM** (0 – 0.7 m/s) | **Hall sensors** | The 3 hall sensors give 6 states per electrical revolution = 96 steps per drum turn (every 3.75°, about every 14 mm of line). The VESC uses the measured **hall table** to know which rotor angle each state means. Works at standstill. |
| **500 – 2000 ERPM** (0.7 – 2.8 m/s) | **Hall sensors, interpolated** | Between two hall edges the VESC estimates the angle from the current speed, so the position is smooth instead of in 3.75° steps. |
| **above 2000 ERPM** (above 2.8 m/s) | **Sensorless observer** | The VESC calculates the position from the back-EMF (the voltage the turning motor generates), using R, L and flux linkage from the motor measurement. More precise at speed. |

This is why hall mode matters on the winch: pre-tension with the pilot standing, brake ↔ pull transitions, braking to standstill and autostop all happen **below 2.8 m/s**, where the sensorless observer is weak and the hall sensors are reliable.

### And HFI?
**HFI (high frequency injection) is not used on this winch.** HFI is a separate sensor mode (`foc_sensor_mode` = HFI and its variants) for motors **without** sensors: the VESC injects an audible high-frequency signal to find the rotor position at standstill. It needs careful tuning. The `foc_hfi_*` values in the config are just defaults and have no effect in hall mode.

For comparison, **sensorless mode** (`foc_sensor_mode = 0`, used until 2026-09-30): below the observer's working range the VESC starts "blind" in open loop up to `foc_openloop_rpm` (150 ERPM) and hopes the rotor follows. Under load this can jitter or twitch backwards, which is exactly what hall mode avoids.

### Where to see and set it
- **Motor Settings → FOC → General → Sensor Mode**: `Hall Sensors` (not Sensorless, not HFI).
- **Motor Settings → FOC → Hall Sensors** tab: Sensorless ERPM (2000), Hall Interpolation ERPM (500), Hall Table [0]…[7].
- **Motor Settings → General → Sensor Port Mode: Hall Sensors** only says what kind of sensor could be on the port. It does not switch hall mode on.

## 8. Tachometer and line length

The tachometer counts the motor's position steps. As far as known for FW 5.x: **6 counts per electrical revolution = 96 counts per drum turn** (to be verified, see below). Tac counts up and down with direction; Tac ABS only counts up. Both start at 0 when the VESC is switched on (with the line fully wound in).

With the empty drum (circumference ≈ 1.35 m) that is about **71 counts per metre of line**, fewer with line wound on (larger effective diameter).

> ⚠ **Calculated, to be verified:** the autostop patch assumes `1500 counts ≈ 15 m`, and `receiver.ino` assumes 100 counts per metre (it sends `tachometer / 1000` as tens of metres). That fits a drum circumference of about 0.97 m (Robert Zach's winch, 0.31 m drum). On this winch (0.43 m drum) it would mean:
> - the remote shows about **0.71× the real line length**, which matches the observed "about 0.7×" (see CLAUDE.md, known quirks);
> - the VESC autostop triggers at 1500 counts ≈ **21 m** of line left, not 15 m.
>
> Check: pull out a measured length (e.g. 10 m) and read Tac in Realtime Data. Tracked in [WINCH-08](../features/WINCH-08-autostop-docs-verification.md).

## 9. Hall sensor detection (redo only when needed)

Needed again only after changing the motor, the sensor cable or its wiring. Full background: [readme.md](readme.md), "Hall sensors: how they were set up".

1. Backup (section 3).
2. Potentiometer at the "off" end. Winch secured, **line without load, nobody at the drum: the motor turns by itself.**
3. **Motor Settings → FOC → Hall Sensors** tab → start the hall detection (default detection current; increase in small steps if the motor doesn't turn).
4. Check the table: entries **1–6 must have values, 0 and 7 = 255**. Otherwise a sensor or wire is faulty: don't use hall mode.
5. Apply the table, **FOC → General → Sensor Mode = Hall Sensors**, **write** motor configuration.
6. Test with a little potentiometer travel: smooth start and smooth braking at low speed. Then `faults`.
7. Read, save XML, commit.

**Don't use the "Setup Motor FOC" wizard for this.** It also resets current limits, battery and temperature settings.

Result on 2026-09-30: hall table `255, 65, 118, 103, 199, 34, 173, 255` (`foc_hall_table__0` … `__7` in [260930_motor_config.xml](260930_motor_config.xml)).

## 10. Things not to do on the winch

- Firmware update (section 1).
- **Read default** + write.
- Load an old or foreign XML and write it.
- **Setup Motor FOC** wizard without a plan and a backup (resets limits).
- **Setup Input** wizard: it changes the PPM pulse range = how many amps each pull state means (safety-relevant, [WINCH-14](../features/WINCH-14-pull-value-calibration.md)).
- Drive the motor from the control bar at the bottom without securing the winch.
- Brake from high speed (until [WINCH-22](../features/WINCH-22-overvoltage-regen-braking.md) is resolved).

## 11. Smartphone app

*To be completed.* Etienne has the VESC Tool smartphone app. Open points:
- Which version, and does it work with FW 5.3? (Newer app versions may not support FW 5.3 fully or may offer a firmware update: decline it.)
- How does it connect to this VESC (Bluetooth module on the VESC? USB-OTG on Android?)
- Which of the functions above are available in the app (faults, realtime data, reading settings)?

## 12. Worked example: 2026-09-30

1. Red LED with the sensor cable connected → `faults` → `FAULT_CODE_OVER_TEMP_MOTOR`.
2. Backups saved. The XML showed `m_motor_temp_sens_type = 0` (NTC 10k), but the motor has a KTY83-122.
3. Sensor type changed to KTY83/122 (section 6), written → LED off after a restart, potentiometer works.
4. Full speed with the potentiometer, then fast braking → `FAULT_CODE_OVER_VOLTAGE` (72.1 V, up to 88 V shown) → [WINCH-22](../features/WINCH-22-overvoltage-regen-braking.md).
5. Hall detection (section 9), sensor mode Hall, written → smooth start and braking at low speed.
6. New backups committed as `260930_*.xml`, old ones moved to `old/vesc-configs/`.

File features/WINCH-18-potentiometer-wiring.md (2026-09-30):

# WINCH-18: Potentiometer wiring & part spec (ADC2 manual mode)

**Status:** In Progress
**Type:** HW / Doc
**Priority:** P1
**Safety-relevant:** Yes (a wrongly wired, floating or broken potentiometer puts the VESC into manual mode: the winch pulls on its own and ignores the remote)
**Depends on:** –
**Created:** 2026-09-30 · **Last updated:** 2026-09-30

## Motivation
Several places in the docs say a potentiometer must be connected to the VESC's ADC input (ADC2, see [vesc/readme.md](../vesc/readme.md), "Line auto stop in VESC"), and that ADC2 must be connected to GND if no potentiometer is fitted. Without a potentiometer or without the ADC2–GND connection, the winch simply starts pulling at full speed. So far the docs did not say how the potentiometer is wired or what kind of potentiometer to use.

## Scope
- Document the wiring (pin ↔ COMM signal ↔ wire colour) in `vesc/readme.md`.
- Recommend a potentiometer type (resistance, taper, mechanics).
- Document the check after wiring and the failure modes (floating ADC2, broken GND/VCC/wiper wire).

## Out of scope
- VESC firmware, patch, configs (frozen).
- Full autostop documentation and verification: WINCH-08. WINCH-08's open item "poti wiring" is covered by the wiring table here; the remaining WINCH-08 checks (ADC1, direction, voltage at the off end) stay there.

## Changes
- **Hardware:** none so far (documents the existing wiring).
- **VESC:** none (firmware is frozen, see CLAUDE.md)
- **Docs:** `vesc/readme.md`, section "Line auto stop in VESC": subsections "Potentiometer: wiring", "Potentiometer: which part", "Potentiometer: failure modes".

## Wiring (Etienne, 2026-09-30)
Potentiometer viewed from below:

| Potentiometer pin | VESC COMM signal | Wire colour (JST cable) |
|---|---|---|
| left | GND | yellow |
| middle (wiper) | ADC2 | orange |
| right | VCC | red |

## Test plan
### Bench (workshop, no pilot)
- [ ] Voltage on the VCC wire measured: 3.3 V (not 5 V). Value: ___
- [ ] Potentiometer at the "off" end: ADC2 ≈ 0 V (VESC Tool or multimeter). Value: ___ Which end (left/right)? ___
- [ ] Turning slowly: voltage rises smoothly to ≈ 3.3 V; manual mode starts above 0.5 V.
- [ ] Back at the "off" end: winch follows the remote normally.

### Field (real towing)
- [ ] Not needed beyond the WINCH-08 / WINCH-09 pre-flight check (potentiometer at the off end).

## Open questions
- [ ] VCC on the COMM port of this controller: 3.3 V? Pin positions on the COMM port (the Trampa manual shows the newer MKVI revision).
- [ ] Which potentiometer is currently fitted (resistance, taper, part number)?
- [ ] Protect against a broken wiper wire with a pull-down resistor (e.g. 100 kΩ from ADC2 to GND)? This would keep ADC2 near 0 V if the wiper loses contact. It does **not** help against a broken GND wire. Hardware change, needs Etienne's decision.
- [ ] Photo of the wiring for `doc/`?

## Decision log
| Decision | Rationale | Date |
|---|---|---|

## Log
- 2026-09-30: created. Wiring as described by Etienne; wiring, part recommendation, check and failure modes written into vesc/readme.md.

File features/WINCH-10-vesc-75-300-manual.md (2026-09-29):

# WINCH-10: Add Trampa VESC 75/300 user manual to `vesc/`

**Status:** Done
**Type:** Doc
**Priority:** P2
**Safety-relevant:** No
**Depends on:** –
**Created:** 2026-09-28 · **Last updated:** 2026-09-29

## Motivation
The controller in use is the Trampa VESC 75/300. Its manual (connectors, COMM/PPM pinout, limits) is needed for wiring, maintenance and troubleshooting and should be available offline next to the QS motor manuals already in `doc/`.

## Scope
- Find the official manual / datasheet from Trampa for the VESC 75/300 (R3).
- Check whether redistribution in a public repo is allowed. If yes, store it as a PDF in `doc/`; otherwise add the link (and a local copy outside the repo).
- Reference it from `vesc/readme.md` and `doc/parts-list.md`.

## Changes
- **Docs:** `doc/`, `vesc/readme.md`, `doc/parts-list.md`.

## Open questions
- [x] Does Etienne already have a copy? Yes, added as `vesc/VESC-75-300-MKIV-MANUAL.pdf`
- [x] Does the manual match the installed controller? No: it describes the newer **MKVI** revision. The winch's controller (`75_300_R3`) has Mini-USB instead of USB-C, and its power-switch connector sits elsewhere. Noted in vesc/readme.md.
- [ ] The PDF filename says "MKIV", while the manual's title reads "MKVI". Rename the PDF if the filename is wrong.
- [ ] Are the motor's hall sensors connected to the VESC sensor port? (Etienne to check; TODO in vesc/readme.md.)

## Log
- 2026-09-28: created
- 2026-09-28: manufacturer specs (product page) added to vesc/readme.md; the PDF manual itself is still open
- 2026-09-28: manual PDF added by Etienne as vesc/VESC-75-300-MKIV-MANUAL.pdf and linked from vesc/readme.md
- 2026-09-29: wiring & safety notes from the manual (warning, power path, connectors, LED codes, power switch) summarised in vesc/readme.md; no separate Markdown transcript stored (PDF stays the source)
- 2026-09-29: Etienne: the manual covers the newer MKVI revision (installed controller has Mini-USB, power-switch connector elsewhere). Power switch on the winch: open = off, closed = on. vesc/readme.md adjusted

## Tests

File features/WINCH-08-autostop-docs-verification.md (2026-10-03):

# WINCH-08: Autostop documentation & verification

**Status:** Planned
**Type:** Doc / VESC (read-only)
**Priority:** P0
**Safety-relevant:** Yes
**Depends on:** WINCH-01, WINCH-16 (tachometer / UART must be understood first)
**Created:** 2026-09-28 · **Last updated:** 2026-10-02

## Motivation
Autostop protects the azimuth system and the line at the end of the rewind, but only under the right conditions. The README doesn't explain how the potentiometer is wired, which poti position does what, or the limits of the brake. Some of what we "know" comes only from the patch source and isn't verified on the real winch.

## Scope
- Verify on the real winch (VESC Tool, multimeter), **read-only; no firmware or config changes**:
  - [x] actually flashed firmware version (VESC Tool → Firmware), expected 5.x patched → **FW 5.3**, HW 75_300_R3 (read out by Etienne with VESC Tool 3.01, 2026-09-30)
  - [ ] poti wiring: which pins go to 3.3 V / GND / ADC2 on the COMM port (poti side documented in [WINCH-18](WINCH-18-potentiometer-wiring.md); VCC voltage and COMM pin positions still open)
  - [ ] ADC1: connected? To what? Does ADC1 > 3 V really enable autostop in manual mode (patch line 34)?
  - [ ] voltage at ADC2 with poti fully at the "off" end (must be < 0.5 V)
  - [ ] direction: which way is "off" (Etienne's notes say "fully left", to be confirmed)
- Write a README section "Autostop & potentiometer":
  - wiring diagram / pin table
  - poti positions ↔ function (off/normal PPM operation vs. manual rewind with proportional current 0–35 A)
  - what autostop does (≈15 m line left → 18 A brake) and what the receiver-side taper does
  - ⚠ the rewind rule (max. state 2, from WINCH-01) repeated here
  - recovery procedure: line on the ground / remote switched off too early → gently turn the poti to rewind
- Document open points (tachometer units RX vs. patch; Etienne's observation that line length reads ~0.7× too short).
  - **Hypothesis (2026-09-30, calculated):** both come from the drum size. 96 tachometer counts per drum turn (16 pole pairs × 6); `receiver.ino` assumes 100 counts/m and the patch 1500 counts ≈ 15 m, which fits Robert's ~0.97 m drum circumference. This winch's drum: 0.43 m → ≈ 1.35 m circumference → ≈ 71 counts/m → display ≈ 0.71× real length (matches the observation), autostop at ≈ 21 m line left instead of 15 m. Details: [vesc/vesc-tool-guide.md](../vesc/vesc-tool-guide.md) section 8.
  - [ ] Verify: pull out a measured length (e.g. 10 m, soft brake), read `Tac` in VESC Tool Realtime Data. Expected ≈ 710 counts on the empty drum if the hypothesis is right.

## Out of scope
- Any change to VESC firmware, patch or configs (frozen, see CLAUDE.md).
- Fixing the line-length offset.

## Changes
- **VESC:** none (read-only verification).
- **Docs:** README.md, possibly `vesc/readme.md`.

## Test plan
### Bench
- [ ] Poti at off end → winch follows the remote normally.
- [ ] Poti turned slightly → winch pulls gently regardless of the remote (manual mode).
- [ ] Autostop triggers at ≈15 m remaining line with a low rewind pull (state ≤2). Measure the remaining distance.

## Open questions
- [ ] All verification items above.
- [ ] Should a photo of the poti wiring go into `doc/`?

## Decision log
| Decision | Rationale | Date |
|---|---|---|
| Autostop docs are based on verified facts only; unverified items are marked as such | Safety documentation must not guess | 2026-09-28 |
| Stay on FW 5.3 with the autostop patch (`vesc/vesc_75_300_auto_stop.bin`); no firmware update | Etienne's decision: proven in operation; FW 6.x would drop the line autostop. Consequence: no VESC Express (needs FW 6.x + VESC Tool 6.x), so no SD-card logging via CAN for now | 2026-10-02 |

## Log
- 2026-09-28: created
- 2026-09-30: FW 5.3 confirmed (VESC Tool 3.01). Observed in the same session: the VESC-internal tachometer counts (see WINCH-16). Over-voltage fault when braking from full speed → WINCH-22.
- 2026-10-02: Etienne confirms the flashed firmware is exactly `vesc/vesc_75_300_auto_stop.bin` from this repo (built by Robert Zach, not compiled by Etienne) and that he has operated the winch with it several times. Still open: whether every detail of `vesc_ppm_auto_stop.patch` (e.g. the ADC1 > 3 V condition in manual mode) is in that binary, since it was not built from the patch here.

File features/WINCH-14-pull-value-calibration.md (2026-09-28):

# WINCH-14: Pull-value calibration procedure

**Status:** Idea
**Type:** Doc
**Priority:** P2
**Safety-relevant:** Yes (actual pull on the pilot)
**Depends on:** –
**Created:** 2026-09-28 · **Last updated:** 2026-09-28

## Motivation
From the old README ToDo and Robert's notes: the "kg" values in the code only match reality if the VESC current settings are calibrated. Robert measured about 3.6 A/kg with a QS260 hub motor using a suitcase scale. A documented, repeatable procedure is missing.

## Idea
- Document a measurement procedure (fixed anchor, luggage/crane scale, measure each state).
- Record measured kg per state in a table in the manual (WINCH-09).
- **No** VESC config change without Etienne's explicit decision (VESC is frozen); adjustments would go through `myMaxPull` / scale values, which is safety-relevant.

## Log
- 2026-09-28: created as idea (from old README ToDo)
- 2026-09-28: ToDo removed from README.md; this file is now the only place it is tracked.

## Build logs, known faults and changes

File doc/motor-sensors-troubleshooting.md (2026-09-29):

# Motor-Sensoren testen: Temperaturfühler und 3 Hall-Sensoren

> Ausnahmsweise auf Deutsch. Gilt für den QS Motor 12kW 260 V4 der Winde mit 6-poligem Sensorstecker (3 Hall-Sensoren + Temperaturfühler). Hintergrund und Einbindung im VESC: [vesc/readme.md](../vesc/readme.md) ("Background: sensorless vs. hall sensors", "Recommendation: connect and use the hall sensors") und [WINCH-17](../features/WINCH-17-hall-sensors-foc.md).

Benötigt: Multimeter, Labornetzteil, 3 Widerstände (4,7 bis 10 kΩ), am besten auch 3 LEDs mit je 1 kΩ Vorwiderstand.

## Pinbelegung

| Kabelfarbe | Funktion |
|---|---|
| Schwarz | GND für Temperaturfühler und Hall (gemeinsamer Minuspol) |
| Rot | Hall+ (Versorgung) |
| Pin oben Mitte (Farbe nicht angegeben) | Temperaturfühler+ |
| Blau, Grün, Gelb | vermutlich die drei Hall-Ausgänge |

Hinweis: Die zugrunde liegende Anschlussgrafik zeigt nicht, ob man auf die Steckerseite oder die Kabelseite schaut. Orientiere dich an den Kabelfarben, nicht an der Position im Stecker. Das Kabel für den Temperaturfühler findest du über die Messung in Schritt 2.

## Vorbereitung

- **VESC ausschalten und Batterie abklemmen.** Dann den Motor komplett vom VESC trennen: Sensorstecker abziehen, die drei dicken Phasenkabel abstecken. Die Phasenkabel dürfen sich nicht berühren und nicht offen herumliegen.
- Die Winde sichern, sodass sich die Trommel gefahrlos von Hand drehen lässt (Seil entlastet). Beim Nabenmotor dreht sich das Gehäuse mit der Trommel, die Achse steht fest.
- Die drei Widerstände (4,7 bis 10 kΩ) werden als Pull-ups benötigt. Die Hall-Ausgänge sind meist Open-Collector, also ohne eigenen Pull-up. Ohne Widerstand lässt sich der High-Zustand nicht zuverlässig messen.
- Klemmleisten, Krokoklemmen oder Dupont-Stecker erleichtern das Greifen der einzelnen Kabel.

## Schritt 1: Kurzschluss- und Isolationsprüfung (stromlos)

Multimeter auf Widerstand oder Durchgang stellen:

- Zwischen je zwei der 6 Pins darf kein Kurzschluss sein. Ausnahme: Zwischen Rot und Schwarz kann ein endlicher Widerstand oder ein Diodenverhalten auftreten, das ist normal.
- Zwischen jedem Pin und dem Motorgehäuse sowie den Phasenkabeln sollte der Widerstand praktisch unendlich sein (OL).

## Schritt 2: Temperaturfühler prüfen

Nicht mit dem Netzteil speisen, das erwärmt den Sensor und kann ihn beschädigen. Multimeter auf Widerstand stellen und zwischen Schwarz und dem Kandidaten-Pin messen. Der richtige Pin zeigt einen Widerstand im Bereich von etwa 0,3 bis 100 kΩ.

Bei Raumtemperatur (ca. 25 °C) verrät der Wert den Sensortyp:

| Messwert bei ca. 25 °C | Sensortyp | Verhalten beim Erwärmen |
|---|---|---|
| ca. 10 kΩ | NTC 10k (meist B3380/B3950) | Widerstand sinkt |
| ca. 1,0 kΩ | KTY83-122 | Widerstand steigt (ca. 0,8 % pro °C) |
| ca. 1,1 kΩ | PT1000 | Widerstand steigt (ca. 0,4 % pro °C) |
| ca. 0,6 kΩ | KTY84-130 | Widerstand steigt |

KTY83 und PT1000 liegen bei Raumtemperatur nah beieinander. Unterscheiden lassen sie sich über die Änderung beim Erwärmen (KTY83 steigt etwa doppelt so stark) oder über das Datenblatt / die Bestellangaben von QS.

Zur Kontrolle den Motor erwärmen, z. B. mit einem Föhn auf das Gehäuse. Weil der Fühler in der Wicklung sitzt, reagiert er träge. Richtwerte für einen 10k-NTC (B3950): 0 °C ≈ 33 kΩ, 40 °C ≈ 5,3 kΩ, 60 °C ≈ 2,5 kΩ.

Ein Fehler liegt vor bei:

- OL oder unendlichem Widerstand (Fühler oder Kabel unterbrochen),
- nahe 0 Ω (Kurzschluss),
- einem Wert, der sich beim Erwärmen nicht ändert.

Den Sensortyp brauchst du später im VESC Tool: Motor Settings, Einstellung `m_motor_temp_sens_type`. Welche Typen dort zur Auswahl stehen, hängt von der Firmware-Version ab. Die Configs im Repo sind hier uneinheitlich (Robert: `2`, Etienne 2024: `0`), siehe [WINCH-17](../features/WINCH-17-hall-sensors-foc.md).

## Schritt 3: Hall-Sensoren prüfen

### Aufbau

1. Netzteil auf 5,0 V einstellen (übliche VESC-Sensorversorgung) und die Strombegrenzung auf ca. 30 mA setzen.
2. Plus an Rot, Minus an Schwarz anschließen.
3. Je einen Widerstand (4,7 bis 10 kΩ) zwischen Rot und jeden Signalpin (Blau, Grün, Gelb) klemmen oder löten.
4. Netzteil einschalten. Für drei Sensoren sind grob 10 bis 30 mA normal. Geht das Netzteil sofort in die Strombegrenzung, sofort abschalten und Polarität und Kurzschlüsse prüfen.

### Funktionstest pro Sensor

Multimeter auf DC-Spannung, schwarze Prüfspitze an Schwarz (GND), rote Prüfspitze nacheinander an Blau, Grün, Gelb. Dabei die Trommel langsam von Hand drehen.

- Jeder Kanal muss zwischen Low (ca. 0 bis 0,5 V) und High (ca. 4,5 bis 5 V) umschalten.
- Pro Umdrehung schaltet jeder Kanal so oft komplett durch, wie der Motor Polpaare hat. **Der QS-Motor hat 32 Magnete = 16 Polpaare, also 16 volle Zyklen pro Umdrehung** (laut Config `si_motor_poles = 32`).
- Bleibt ein Kanal immer Low, immer High oder wackelt er unruhig, ist der Sensor oder seine Leitung defekt.

### Phasenlage prüfen

Die drei Signale müssen zueinander um 120° elektrisch versetzt sein, sonst funktioniert die Kommutierung nicht.

Bei 16 Polpaaren gibt es 16 × 6 = 96 Zustandswechsel pro Umdrehung, also etwa alle 3,75°. Von Hand ist das fein. **Am einfachsten geht es deshalb mit drei LEDs:** je eine LED mit 1 kΩ Vorwiderstand zwischen Rot (+5 V) und den Signalpin schalten. Die LED leuchtet, wenn der Ausgang Low ist. So siehst du alle drei Kanäle gleichzeitig.

Vorgehen:

1. Die Trommel in kleinen Schritten drehen und bei jeder Position alle drei Kanäle ablesen (0 = Low, 1 = High). Eine Markierung mit Klebeband auf der Trommel hilft bei der Orientierung.
2. Die Zustände in eine Tabelle eintragen.
3. Zwei Regeln prüfen:
   - Der Zustand 000 oder 111 darf nie vorkommen.
   - Zwischen zwei aufeinanderfolgenden Zuständen ändert sich immer genau ein Bit.

Eine gültige Sequenz sieht z. B. so aus: 001 → 011 → 010 → 110 → 100 → 101 → wieder 001. Reihenfolge, Richtung oder Bitzuordnung dürfen anders sein, entscheidend sind die zwei Regeln.

## Schritt 4: Abschlusstest am VESC

Sind die Messungen in Ordnung, den Sensorstecker am Sensor-Port des VESC anschließen. Achtung: Das Trampa-Handbuch im Repo beschreibt die neuere MKVI-Revision. Lage und Belegung des Ports am eingebauten Controller vor Ort prüfen (siehe [vesc/readme.md](../vesc/readme.md)).

Dann im VESC Tool die Hall-Erkennung durchführen, wie in [vesc/readme.md](../vesc/readme.md) unter "Recommendation: connect and use the hall sensors" beschrieben. **Der Motor dreht sich dabei selbst: Seil entlastet, niemand an der Trommel.**

- Eine erfolgreiche Erkennung erzeugt die Hall-Tabelle: Einträge 1 bis 6 haben Werte, nur 0 und 7 stehen auf 255.
- Die Zuordnung der drei Signalkabel zu H1, H2 und H3 ist unkritisch, weil die Erkennung die Reihenfolge selbst ermittelt.
- In den Echtzeitdaten die Motortemperatur prüfen: Bei kaltem Motor muss sie etwa der Umgebungstemperatur entsprechen.

## Fehlersuche

| Symptom | Wahrscheinliche Ursache |
|---|---|
| Netzteil geht in die Strombegrenzung | Rot/Schwarz vertauscht oder Kurzschluss im Kabel |
| Ein Kanal bleibt konstant | Sensor oder Leitung defekt, oder Pull-up fehlt |
| Alle Kanäle schwingen ungleichmäßig oder rauschen | Wackelkontakt im Stecker oder fehlender Pull-up |
| Zustand 000 oder 111 tritt auf | Sensor defekt oder falsch platziert |
| Temperaturwert OL oder ändert sich nicht | Fühlerleitung unterbrochen oder falscher Pin |
| Temperatur im VESC Tool unplausibel, Messung aber in Ordnung | Falscher Sensortyp (`m_motor_temp_sens_type`) eingestellt |

## Messprotokoll

Ergebnisse bitte mit Datum in [WINCH-17](../features/WINCH-17-hall-sensors-foc.md) eintragen (Temperaturfühler: Pin, Messwert, Temperatur, Sensortyp; Hall: Kanäle, Sequenz, Auffälligkeiten).

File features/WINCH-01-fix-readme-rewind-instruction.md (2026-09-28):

# WINCH-01: ⚠ Fix dangerous README rewind instruction

**Status:** Done
**Type:** Doc
**Priority:** P0
**Safety-relevant:** Yes
**Depends on:** –
**Created:** 2026-09-28 · **Last updated:** 2026-09-28

## Motivation
The README usage section ("C) Release") currently says:

> Go To defaultPull (7kg pull value) before you release. Release and move back to fullPull to rewind the line.

This is **wrong and dangerous**. It was Etienne's own earlier assumption. Rewinding with full pull once led to the autostop brake not being able to stop the drum in time: the carabiner was pulled into the azimuth system, the line broke and tangled, and the whole winch had to be rebuilt. (It may have been a cascade of errors, but rewinding with high pull was a key factor.)

## Scope
- Replace the release/rewind instruction in README.md: after release, rewind with **maximum state 2 (prePull)**, never higher.
- Add a prominent warning block explaining why (brake can't hold → carabiner pulled into the azimuth system / line snaps; has happened once).
- Adjust the neighbouring sentence about autostop so it doesn't imply that autostop protects against high-speed rewinds.

## Out of scope
- Poti wiring and positions, the full autostop description → WINCH-08.
- Rewriting the rest of the usage section → WINCH-09 (manual).
- Any code change (e.g. limiting the pull after release in firmware). This could be a later idea, but it is safety-relevant and needs its own feature.

## Changes
- **Docs:** README.md, section "usage → C) Release" only.

## Test plan
- [x] `git diff README.md` shows only the release section changed.
- [x] Etienne reads and approves the wording. (Set to Done by Etienne, 2026-09-28.)

## Open questions
- [ ] Should the transmitter firmware *enforce* this later (e.g. cap at state 2 once line length is short, or after a release is detected)? → new feature if yes.

## Decision log
| Decision | Rationale | Date |
|---|---|---|
| Rewind with max. state 2 (prePull ≈ 15 kg) | Real incident: stronger pull overran the autostop brake and destroyed azimuth system / line | 2026-09-28 |
| Done first, before all other features | Safety-critical and the README is public; others may copy the wrong procedure | 2026-09-28 |

## Log
- 2026-09-28: created
- 2026-09-28: README "C) Release" rewritten + warning block added; awaiting Etienne's review of the wording
- 2026-09-28: prePull value in the rule updated to ~17 kg (WINCH-02: `myMaxPull = 95`). Rule itself unchanged: max. state 2.
- 2026-09-28: set to Done by Etienne. Open question on firmware enforcement stays open for a possible future feature.

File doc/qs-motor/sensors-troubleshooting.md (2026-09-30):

# Motor-Sensoren testen: Temperaturfühler und 3 Hall-Sensoren

> Ausnahmsweise auf Deutsch. Gilt für den QS Motor 12kW 260 V4 der Winde mit 6-poligem Sensorstecker (3 Hall-Sensoren + Temperaturfühler). Hintergrund und Einbindung im VESC: [vesc/readme.md](../../vesc/readme.md) ("Background: sensorless vs. hall sensors", "Recommendation: connect and use the hall sensors") und [WINCH-17](../../features/WINCH-17-hall-sensors-foc.md).

Benötigt: Multimeter, Labornetzteil, 3 Widerstände (4,7 bis 10 kΩ), am besten auch 3 LEDs mit je 1 kΩ Vorwiderstand.

## Pinbelegung

Der Motor hat **zwei Sensorsätze** (je 3 Hall-Sensoren + Temperaturfühler), einer davon ist Reserve. In Benutzung ist **Satz 1** mit selbst angebrachtem Stecker. Satz 2 hat noch den Original-QS-Stecker, war nie angeschlossen und ist ungeprüft.

Belegung Satz 1 (von Etienne bestätigt, 2026-09-30):

| Kabelfarbe am Motor | Kabelfarbe am Stecker | Funktion |
|---|---|---|
| Gelb | Gelb | Hall A |
| Grün | Weiß | Hall B |
| Blau | Rot | Hall C |
| Schwarz | Schwarz | GND für Temperaturfühler und Hall (gemeinsamer Minuspol) |
| Rot | Grün | +5 V (Hall-Versorgung) |
| Silber (im QS-Handbuch "transparent") | Blau | Temperaturfühler |

⚠ **Die Farben am Stecker passen nicht zu den Farben am Motor.** Rot am Stecker ist ein Hall-Signal, Grün am Stecker ist +5 V. Die Farbangaben in den Schritten unten beziehen sich auf die **Kabelfarben am Motor**. Wer am Stecker misst, muss sie über die Tabelle übersetzen.

Weitere Motordaten: [README.md](README.md).

## Vorbereitung

- **VESC ausschalten und Batterie abklemmen.** Dann den Motor komplett vom VESC trennen: Sensorstecker abziehen, die drei dicken Phasenkabel abstecken. Die Phasenkabel dürfen sich nicht berühren und nicht offen herumliegen.
- Die Winde sichern, sodass sich die Trommel gefahrlos von Hand drehen lässt (Seil entlastet). Beim Nabenmotor dreht sich das Gehäuse mit der Trommel, die Achse steht fest.
- Die drei Widerstände (4,7 bis 10 kΩ) werden als Pull-ups benötigt. Die Hall-Ausgänge sind meist Open-Collector, also ohne eigenen Pull-up. Ohne Widerstand lässt sich der High-Zustand nicht zuverlässig messen.
- Klemmleisten, Krokoklemmen oder Dupont-Stecker erleichtern das Greifen der einzelnen Kabel.

## Schritt 1: Kurzschluss- und Isolationsprüfung (stromlos)

Multimeter auf Widerstand oder Durchgang stellen:

- Zwischen je zwei der 6 Pins darf kein Kurzschluss sein. Ausnahme: Zwischen Rot und Schwarz kann ein endlicher Widerstand oder ein Diodenverhalten auftreten, das ist normal.
- Zwischen jedem Pin und dem Motorgehäuse sowie den Phasenkabeln sollte der Widerstand praktisch unendlich sein (OL).

## Schritt 2: Temperaturfühler prüfen

Nicht mit dem Netzteil speisen, das erwärmt den Sensor und kann ihn beschädigen. Multimeter auf Widerstand stellen und zwischen Schwarz und dem Kandidaten-Pin messen. Der richtige Pin zeigt einen Widerstand im Bereich von etwa 0,3 bis 100 kΩ.

Bei Raumtemperatur (ca. 25 °C) verrät der Wert den Sensortyp:

| Messwert bei ca. 25 °C | Sensortyp | Verhalten beim Erwärmen |
|---|---|---|
| ca. 10 kΩ | NTC 10k (meist B3380/B3950) | Widerstand sinkt |
| ca. 1,0 kΩ | KTY83-122 | Widerstand steigt (ca. 0,8 % pro °C) |
| ca. 1,1 kΩ | PT1000 | Widerstand steigt (ca. 0,4 % pro °C) |
| ca. 0,6 kΩ | KTY84-130 | Widerstand steigt |

KTY83 und PT1000 liegen bei Raumtemperatur nah beieinander. Unterscheiden lassen sie sich über die Änderung beim Erwärmen (KTY83 steigt etwa doppelt so stark) oder über das Datenblatt / die Bestellangaben von QS.

**Messung an der Winde (Etienne, 2026-09-30):** 0,97 kΩ bei ca. 25 °C (Satz 1, Silber/Blau gegen Schwarz). Das passt zum KTY83-122, den auch das QS-Handbuch nennt. Der Erwärmungstest steht noch aus.

Zur Kontrolle den Motor erwärmen, z. B. mit einem Föhn auf das Gehäuse. Weil der Fühler in der Wicklung sitzt, reagiert er träge. Richtwerte für einen 10k-NTC (B3950): 0 °C ≈ 33 kΩ, 40 °C ≈ 5,3 kΩ, 60 °C ≈ 2,5 kΩ.

Ein Fehler liegt vor bei:

- OL oder unendlichem Widerstand (Fühler oder Kabel unterbrochen),
- nahe 0 Ω (Kurzschluss),
- einem Wert, der sich beim Erwärmen nicht ändert.

Den Sensortyp brauchst du später im VESC Tool: Motor Settings, Einstellung `m_motor_temp_sens_type`. Zu finden unter Motor Settings → General → Advanced → Motor Temperature Sensor Type. **An der Winde ist seit 2026-09-30 KTY83/122 eingestellt** (vorher NTC 10k, was einen dauerhaften Übertemperatur-Fehler ausgelöst hat), siehe [WINCH-17](../../features/WINCH-17-hall-sensors-foc.md).

## Schritt 3: Hall-Sensoren prüfen

### Aufbau

1. Netzteil auf 5,0 V einstellen (übliche VESC-Sensorversorgung) und die Strombegrenzung auf ca. 30 mA setzen.
2. Plus an Rot, Minus an Schwarz anschließen.
3. Je einen Widerstand (4,7 bis 10 kΩ) zwischen Rot und jeden Signalpin (Blau, Grün, Gelb) klemmen oder löten.
4. Netzteil einschalten. Für drei Sensoren sind grob 10 bis 30 mA normal. Geht das Netzteil sofort in die Strombegrenzung, sofort abschalten und Polarität und Kurzschlüsse prüfen.

### Funktionstest pro Sensor

Multimeter auf DC-Spannung, schwarze Prüfspitze an Schwarz (GND), rote Prüfspitze nacheinander an Blau, Grün, Gelb. Dabei die Trommel langsam von Hand drehen.

- Jeder Kanal muss zwischen Low (ca. 0 bis 0,5 V) und High (ca. 4,5 bis 5 V) umschalten.
- Pro Umdrehung schaltet jeder Kanal so oft komplett durch, wie der Motor Polpaare hat. **Der QS-Motor hat 32 Magnete = 16 Polpaare, also 16 volle Zyklen pro Umdrehung** (laut Config `si_motor_poles = 32`).
- Bleibt ein Kanal immer Low, immer High oder wackelt er unruhig, ist der Sensor oder seine Leitung defekt.

### Phasenlage prüfen

Die drei Signale müssen zueinander um 120° elektrisch versetzt sein, sonst funktioniert die Kommutierung nicht.

Bei 16 Polpaaren gibt es 16 × 6 = 96 Zustandswechsel pro Umdrehung, also etwa alle 3,75°. Von Hand ist das fein. **Am einfachsten geht es deshalb mit drei LEDs:** je eine LED mit 1 kΩ Vorwiderstand zwischen Rot (+5 V) und den Signalpin schalten. Die LED leuchtet, wenn der Ausgang Low ist. So siehst du alle drei Kanäle gleichzeitig.

Vorgehen:

1. Die Trommel in kleinen Schritten drehen und bei jeder Position alle drei Kanäle ablesen (0 = Low, 1 = High). Eine Markierung mit Klebeband auf der Trommel hilft bei der Orientierung.
2. Die Zustände in eine Tabelle eintragen.
3. Zwei Regeln prüfen:
   - Der Zustand 000 oder 111 darf nie vorkommen.
   - Zwischen zwei aufeinanderfolgenden Zuständen ändert sich immer genau ein Bit.

Eine gültige Sequenz sieht z. B. so aus: 001 → 011 → 010 → 110 → 100 → 101 → wieder 001. Reihenfolge, Richtung oder Bitzuordnung dürfen anders sein, entscheidend sind die zwei Regeln.

## Schritt 4: Abschlusstest am VESC

Sind die Messungen in Ordnung, den Sensorstecker am Sensor-Port des VESC anschließen. Achtung: Das Trampa-Handbuch im Repo beschreibt die neuere MKVI-Revision. Lage und Belegung des Ports am eingebauten Controller vor Ort prüfen (siehe [vesc/readme.md](../../vesc/readme.md)).

Dann im VESC Tool die Hall-Erkennung durchführen, wie in [vesc/readme.md](../../vesc/readme.md) unter "Recommendation: connect and use the hall sensors" beschrieben. **Der Motor dreht sich dabei selbst: Seil entlastet, niemand an der Trommel.**

- Eine erfolgreiche Erkennung erzeugt die Hall-Tabelle: Einträge 1 bis 6 haben Werte, nur 0 und 7 stehen auf 255.
- Die Zuordnung der drei Signalkabel zu H1, H2 und H3 ist unkritisch, weil die Erkennung die Reihenfolge selbst ermittelt.
- In den Echtzeitdaten die Motortemperatur prüfen: Bei kaltem Motor muss sie etwa der Umgebungstemperatur entsprechen.

## Fehlersuche

| Symptom | Wahrscheinliche Ursache |
|---|---|
| Netzteil geht in die Strombegrenzung | Rot/Schwarz vertauscht oder Kurzschluss im Kabel |
| Ein Kanal bleibt konstant | Sensor oder Leitung defekt, oder Pull-up fehlt |
| Alle Kanäle schwingen ungleichmäßig oder rauschen | Wackelkontakt im Stecker oder fehlender Pull-up |
| Zustand 000 oder 111 tritt auf | Sensor defekt oder falsch platziert |
| Temperaturwert OL oder ändert sich nicht | Fühlerleitung unterbrochen oder falscher Pin |
| Temperatur im VESC Tool unplausibel, Messung aber in Ordnung | Falscher Sensortyp (`m_motor_temp_sens_type`) eingestellt |

## Messprotokoll

Ergebnisse bitte mit Datum in [WINCH-17](../../features/WINCH-17-hall-sensors-foc.md) eintragen (Temperaturfühler: Pin, Messwert, Temperatur, Sensortyp; Hall: Kanäle, Sequenz, Auffälligkeiten).

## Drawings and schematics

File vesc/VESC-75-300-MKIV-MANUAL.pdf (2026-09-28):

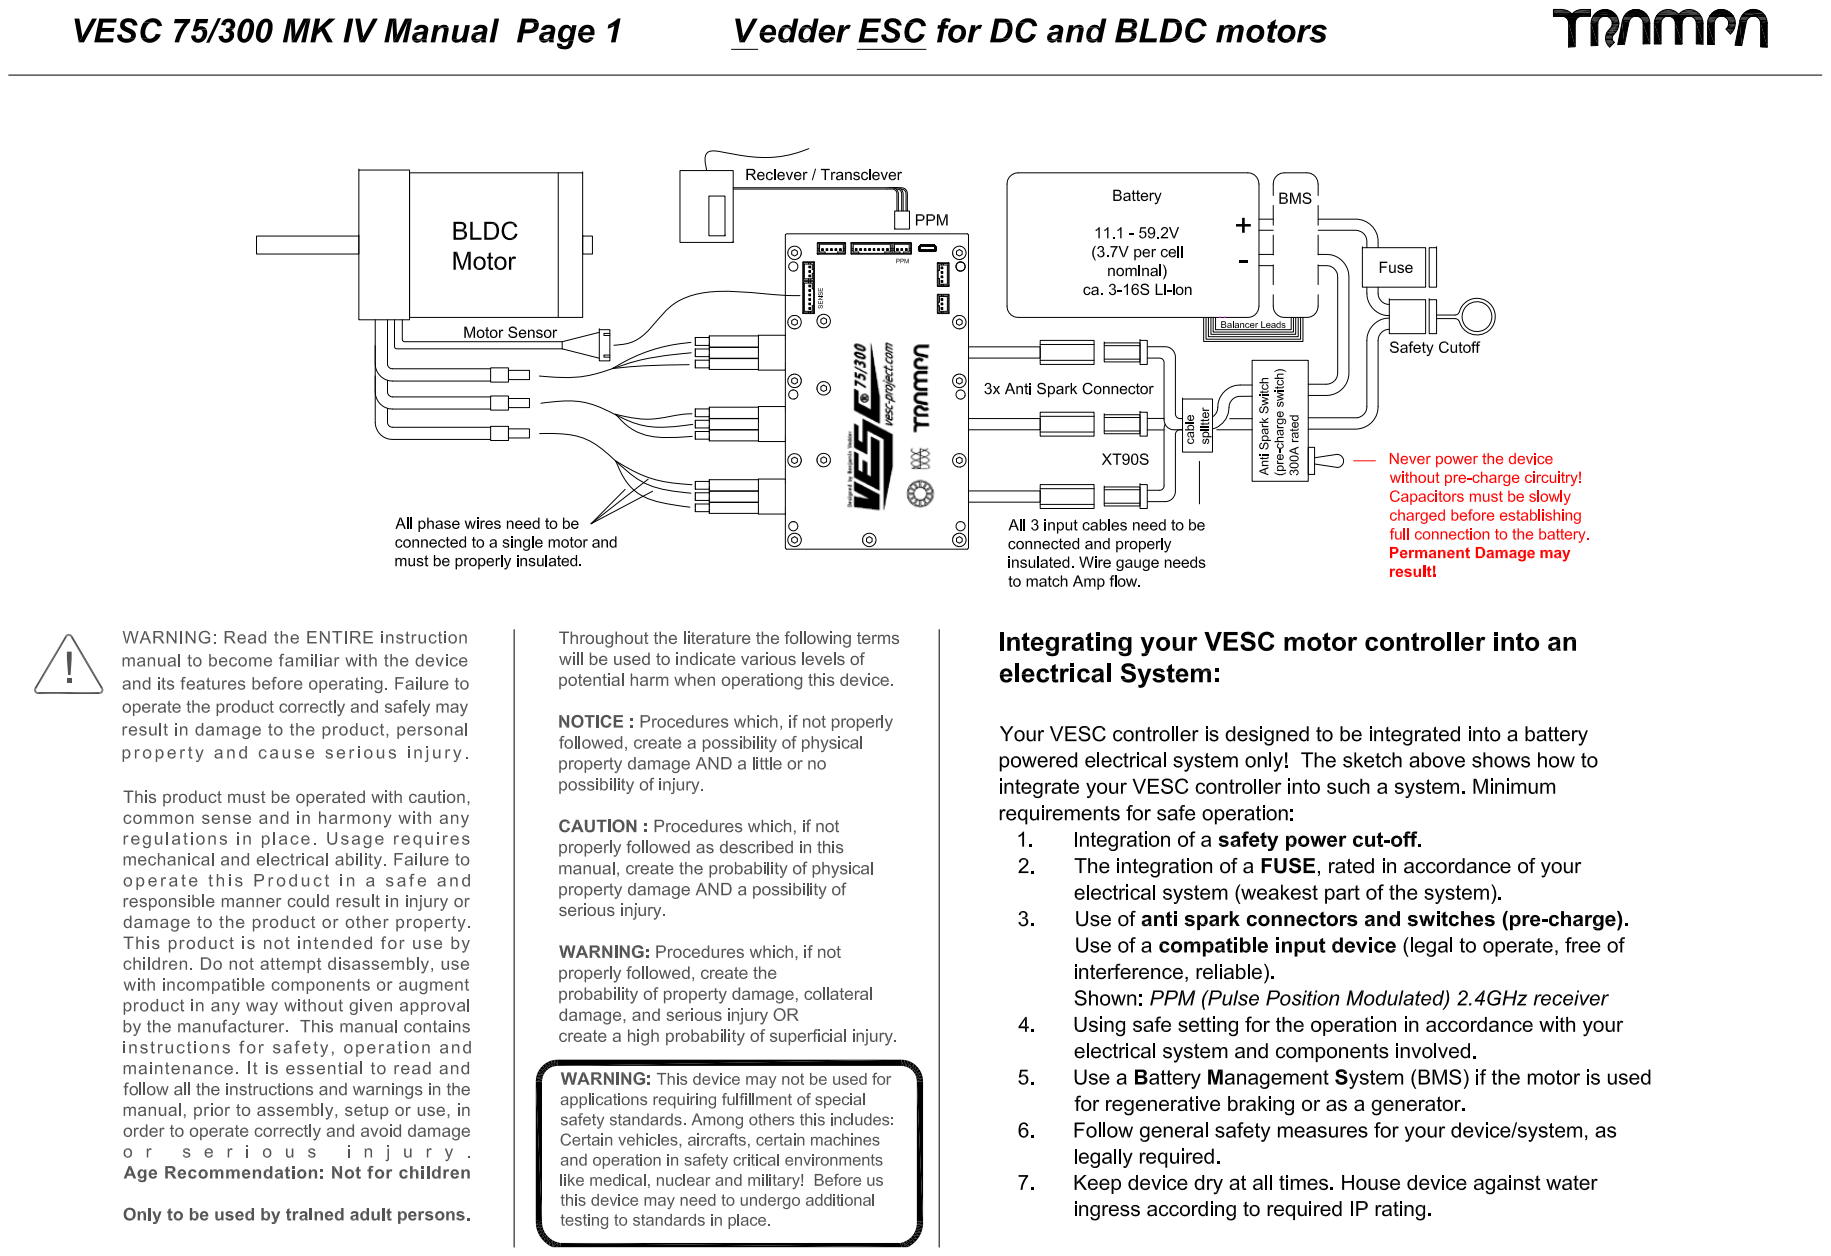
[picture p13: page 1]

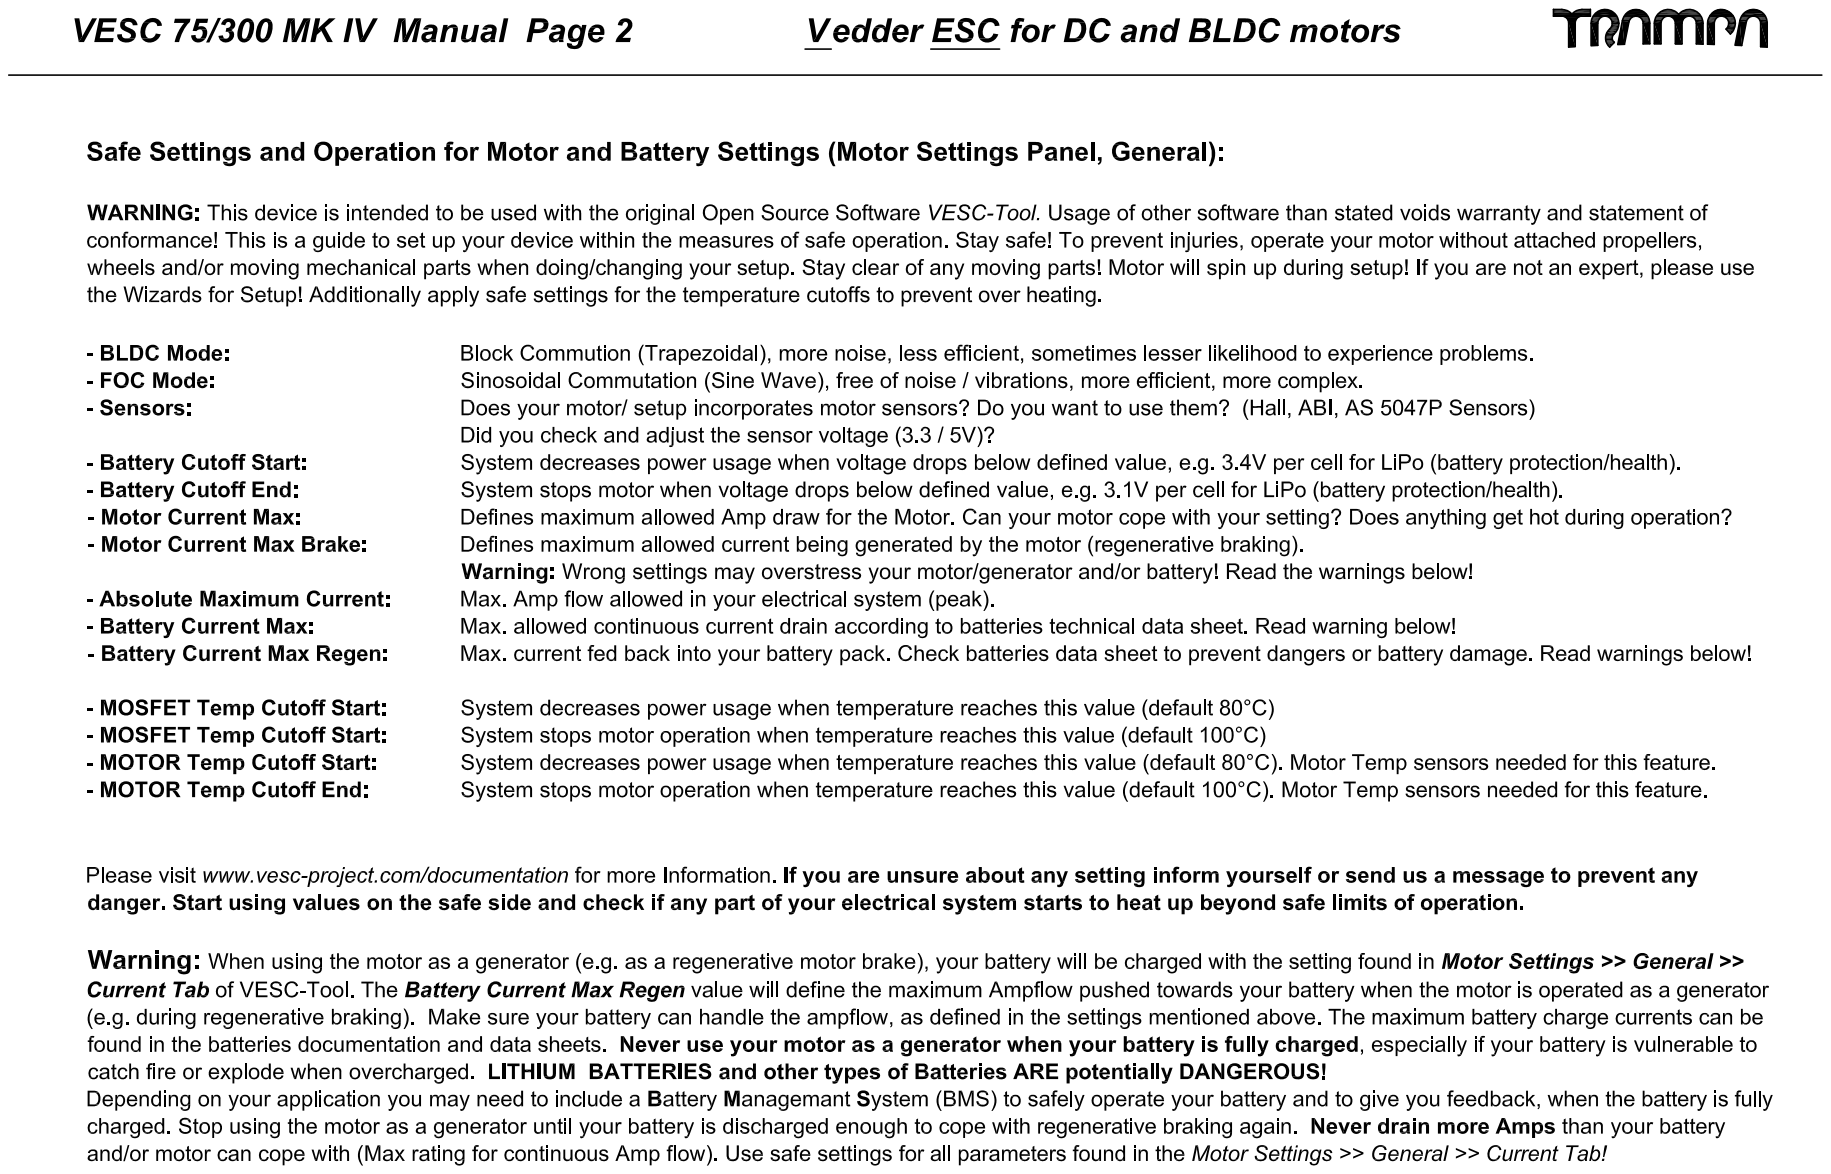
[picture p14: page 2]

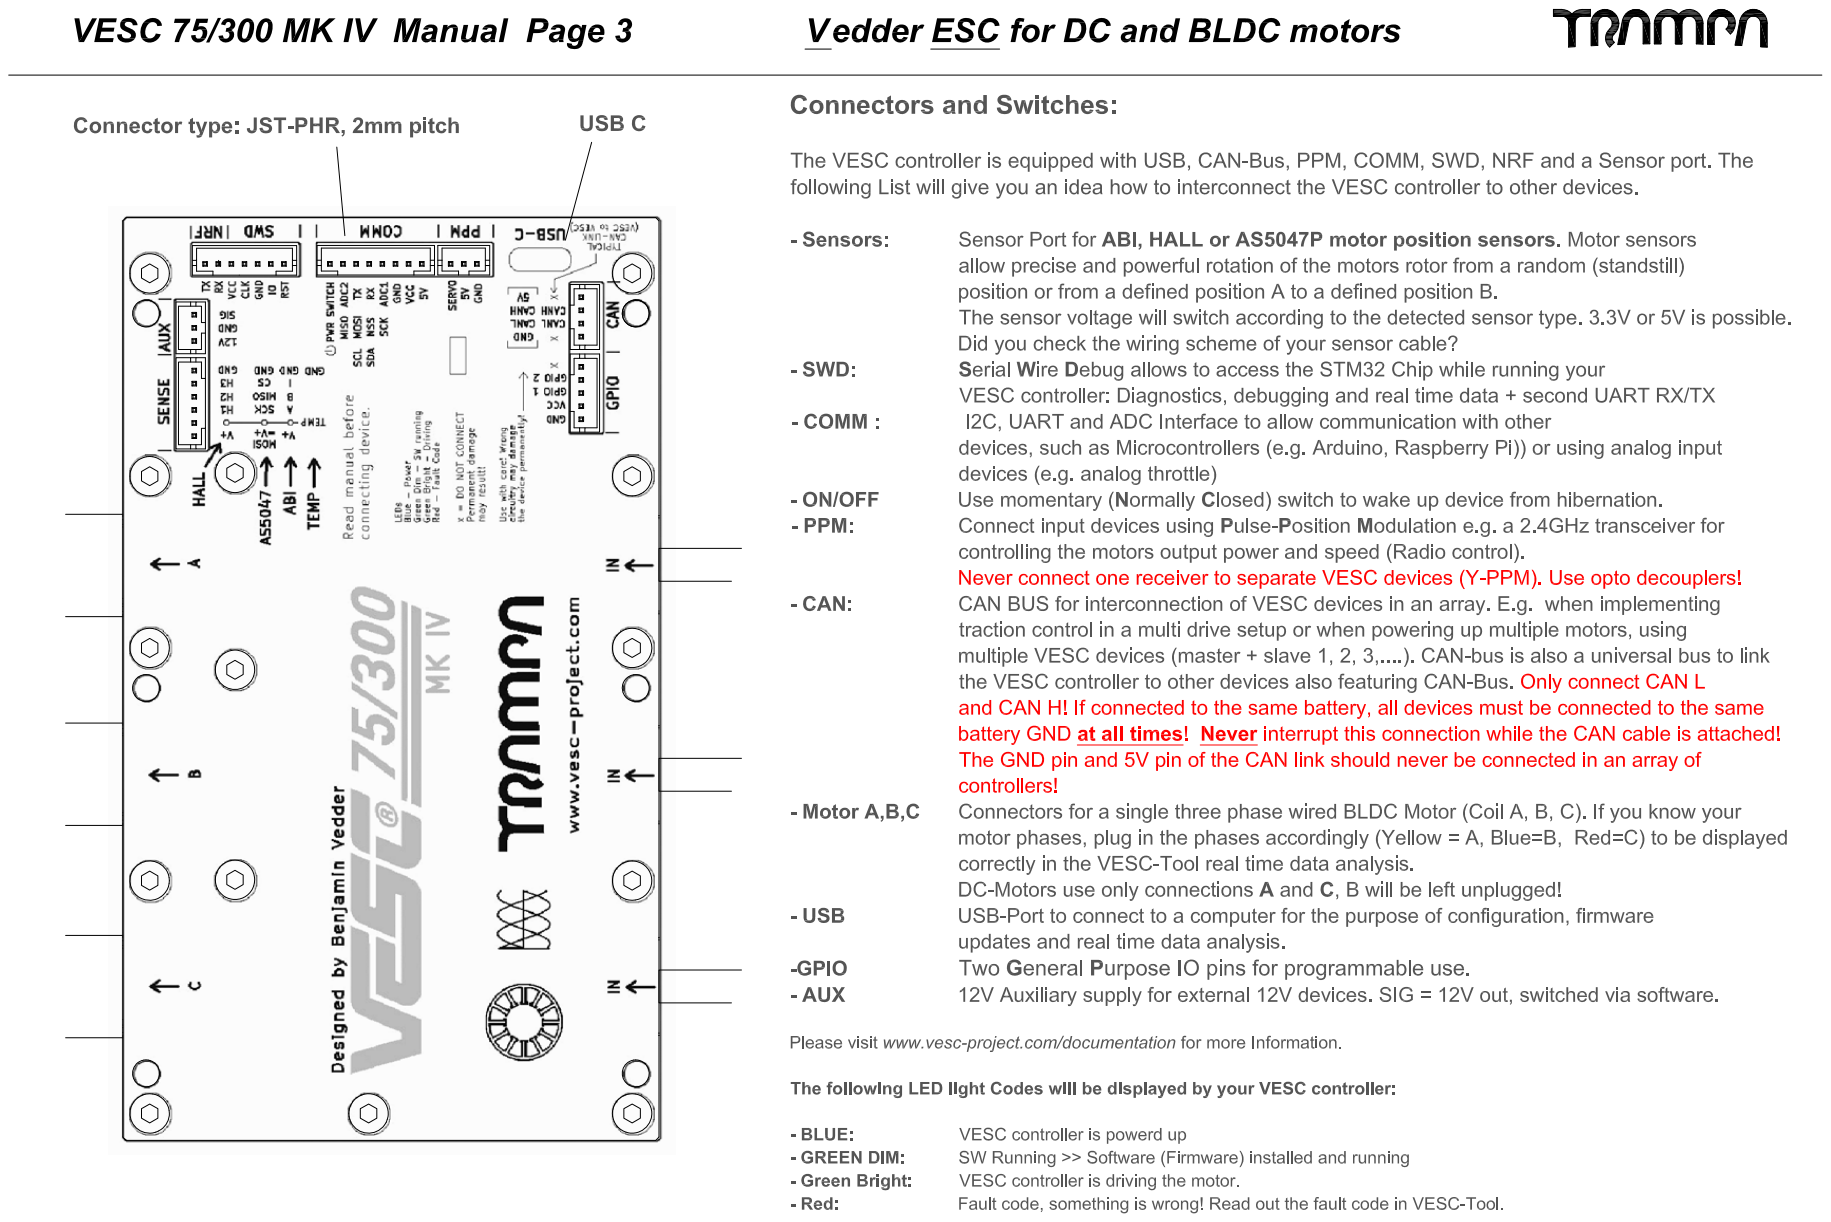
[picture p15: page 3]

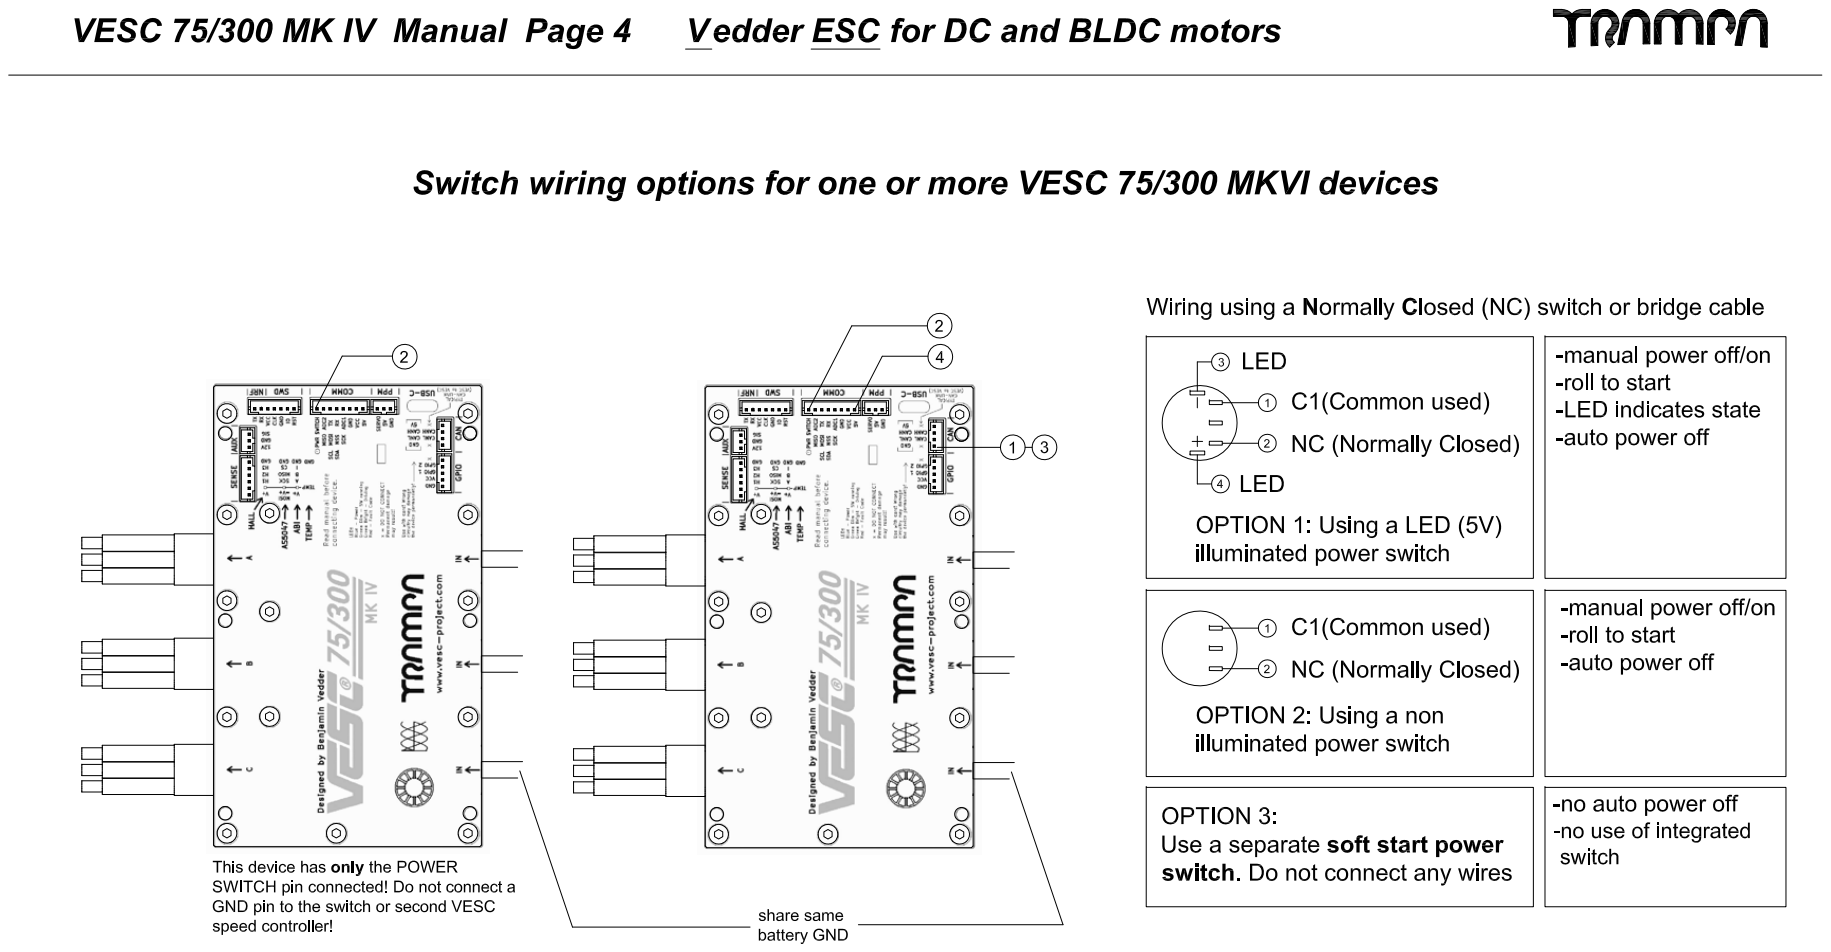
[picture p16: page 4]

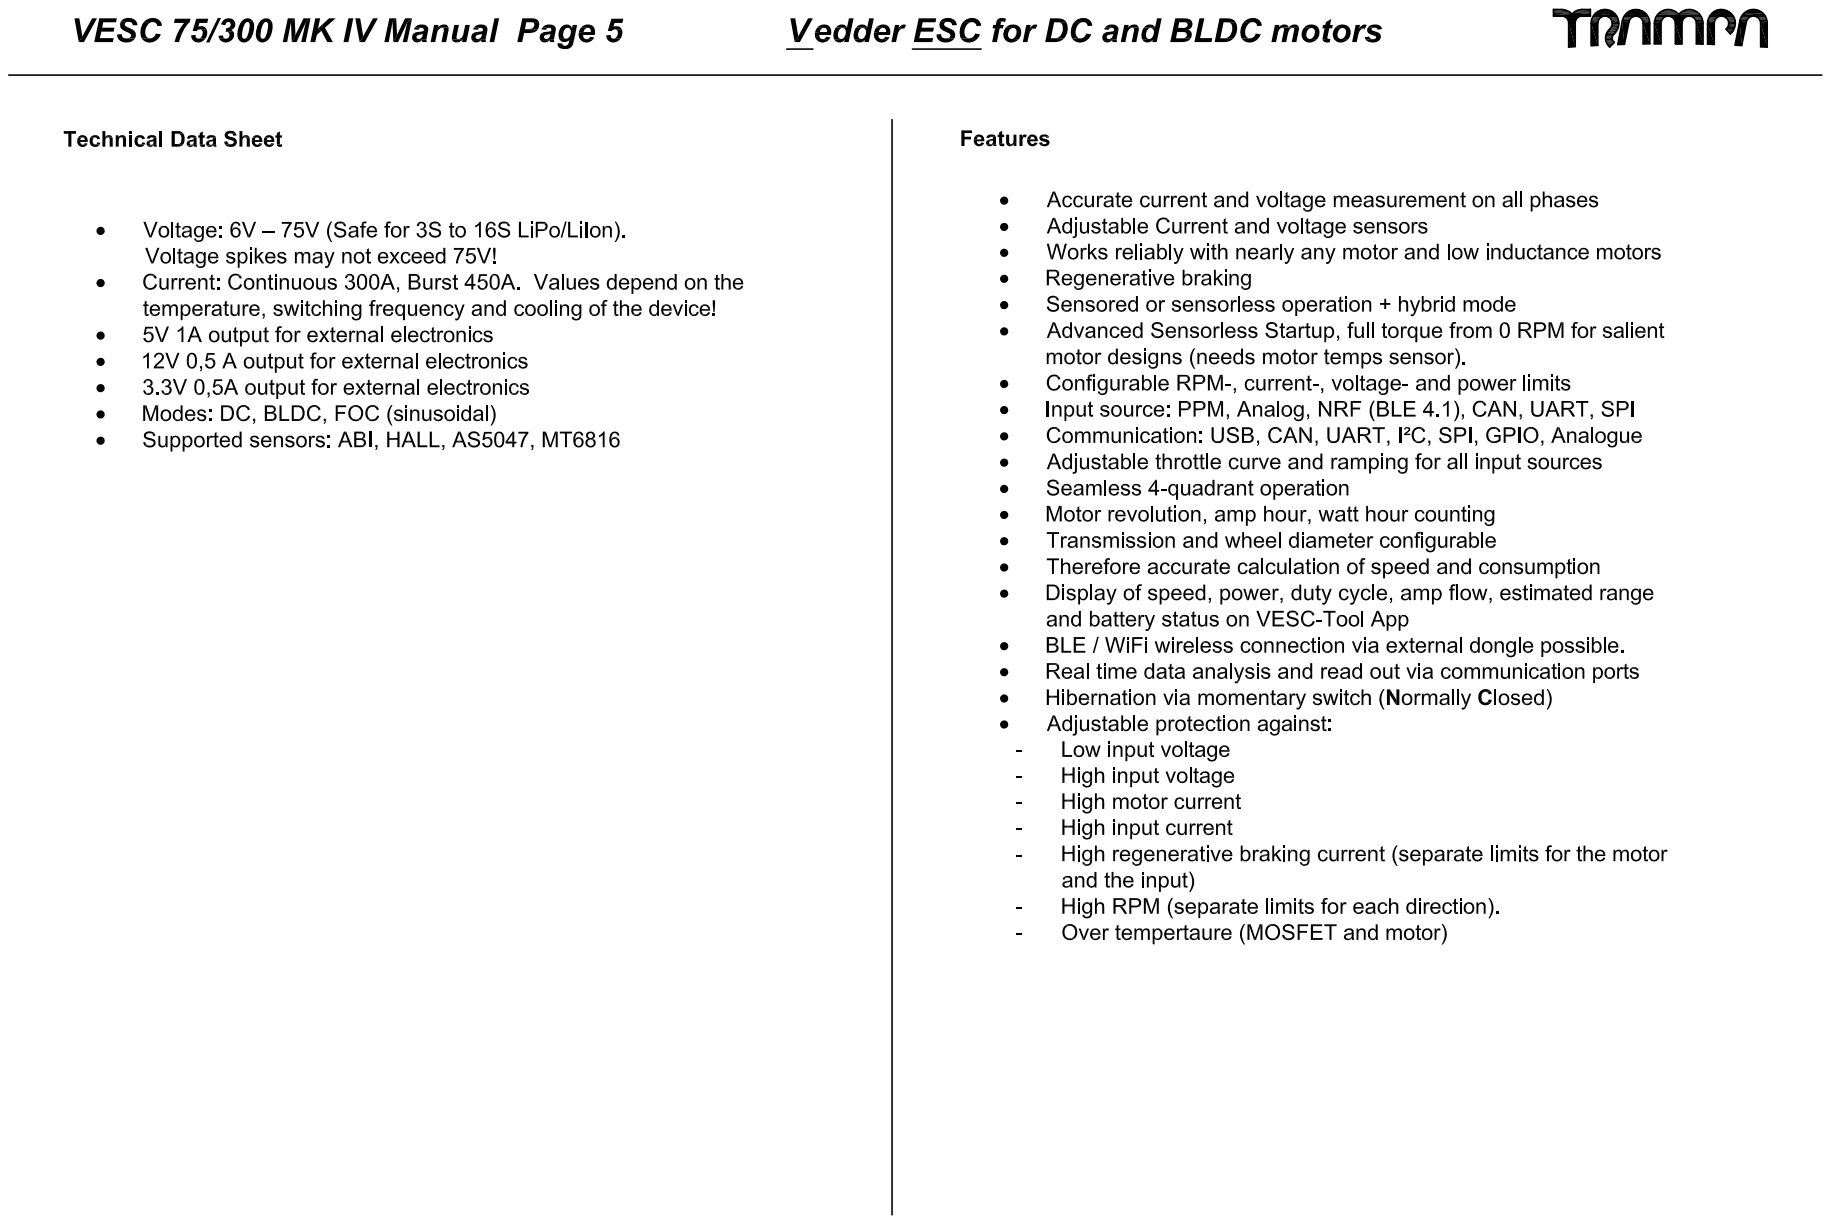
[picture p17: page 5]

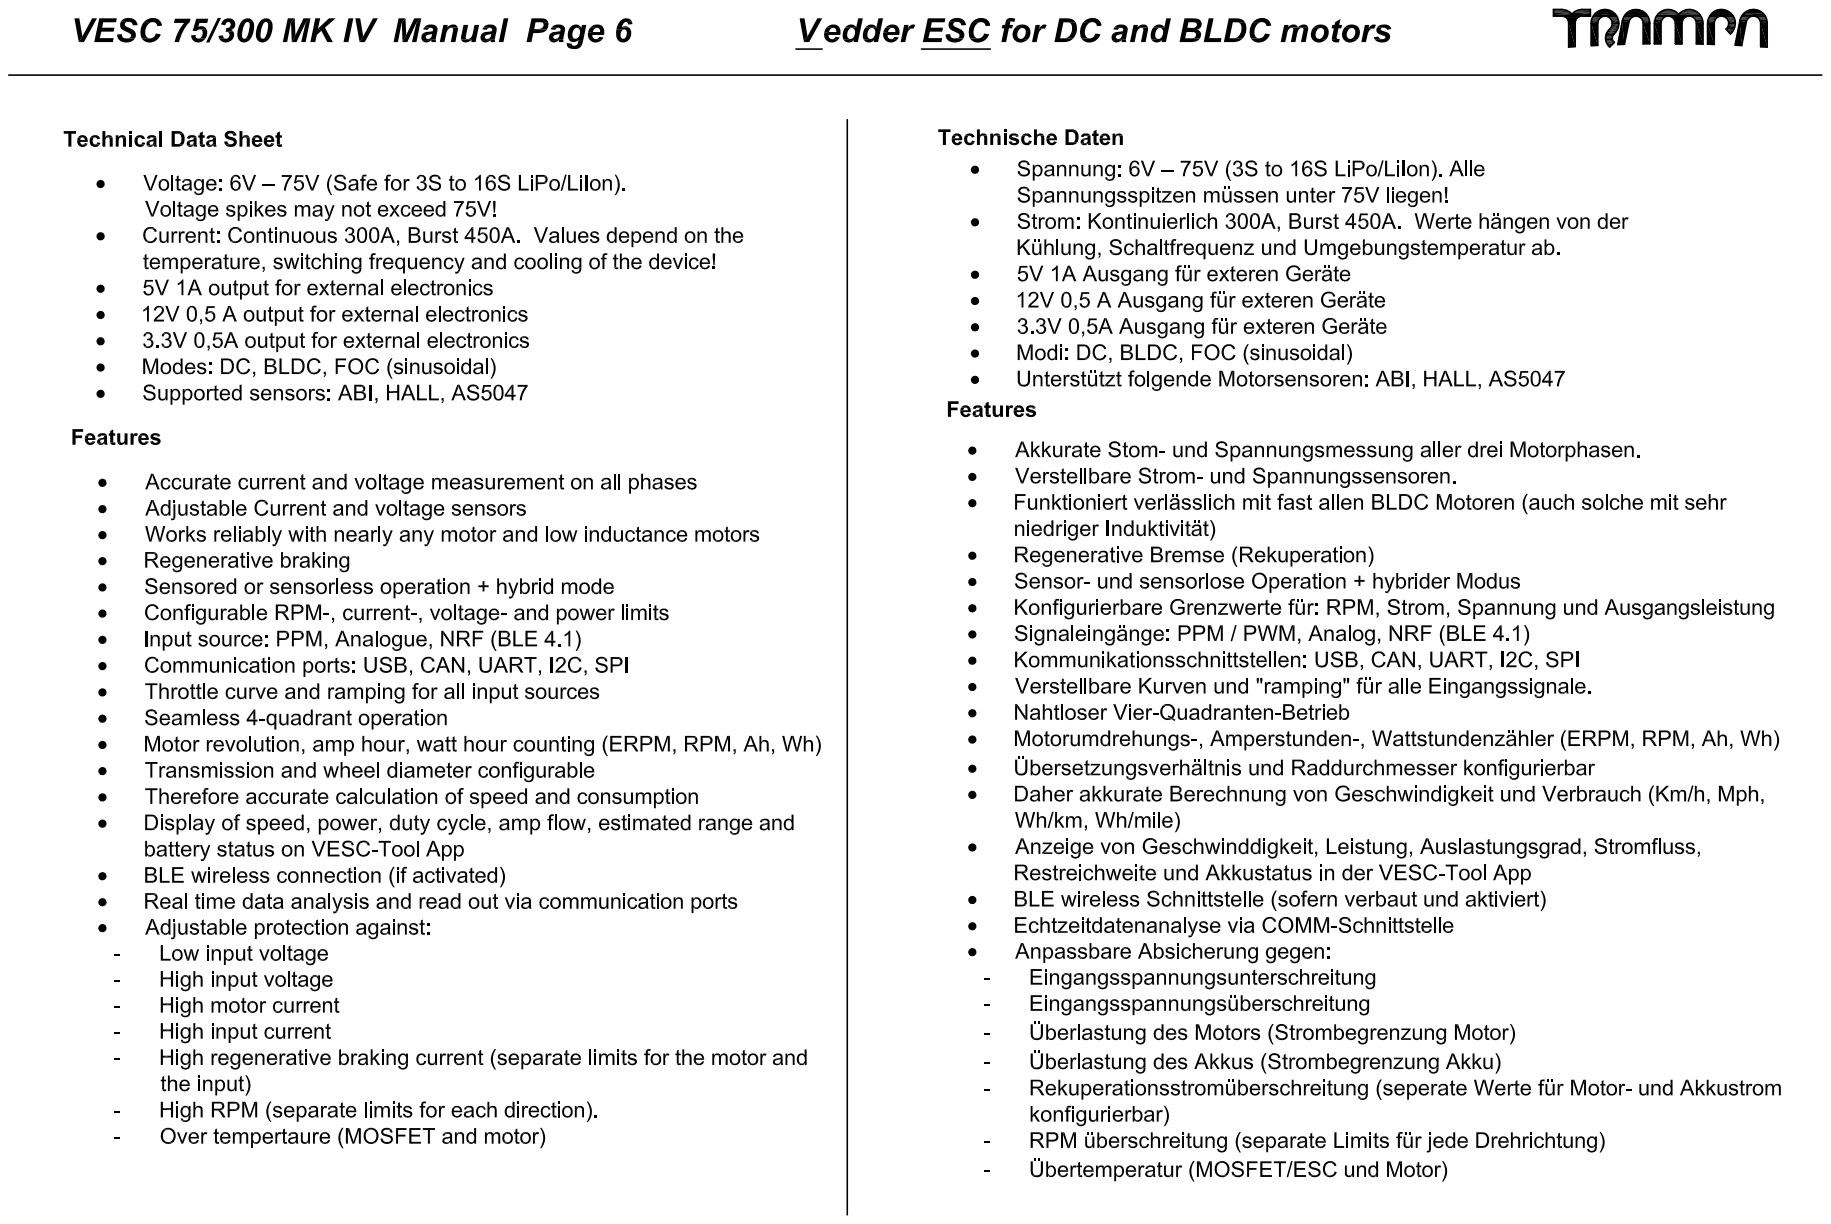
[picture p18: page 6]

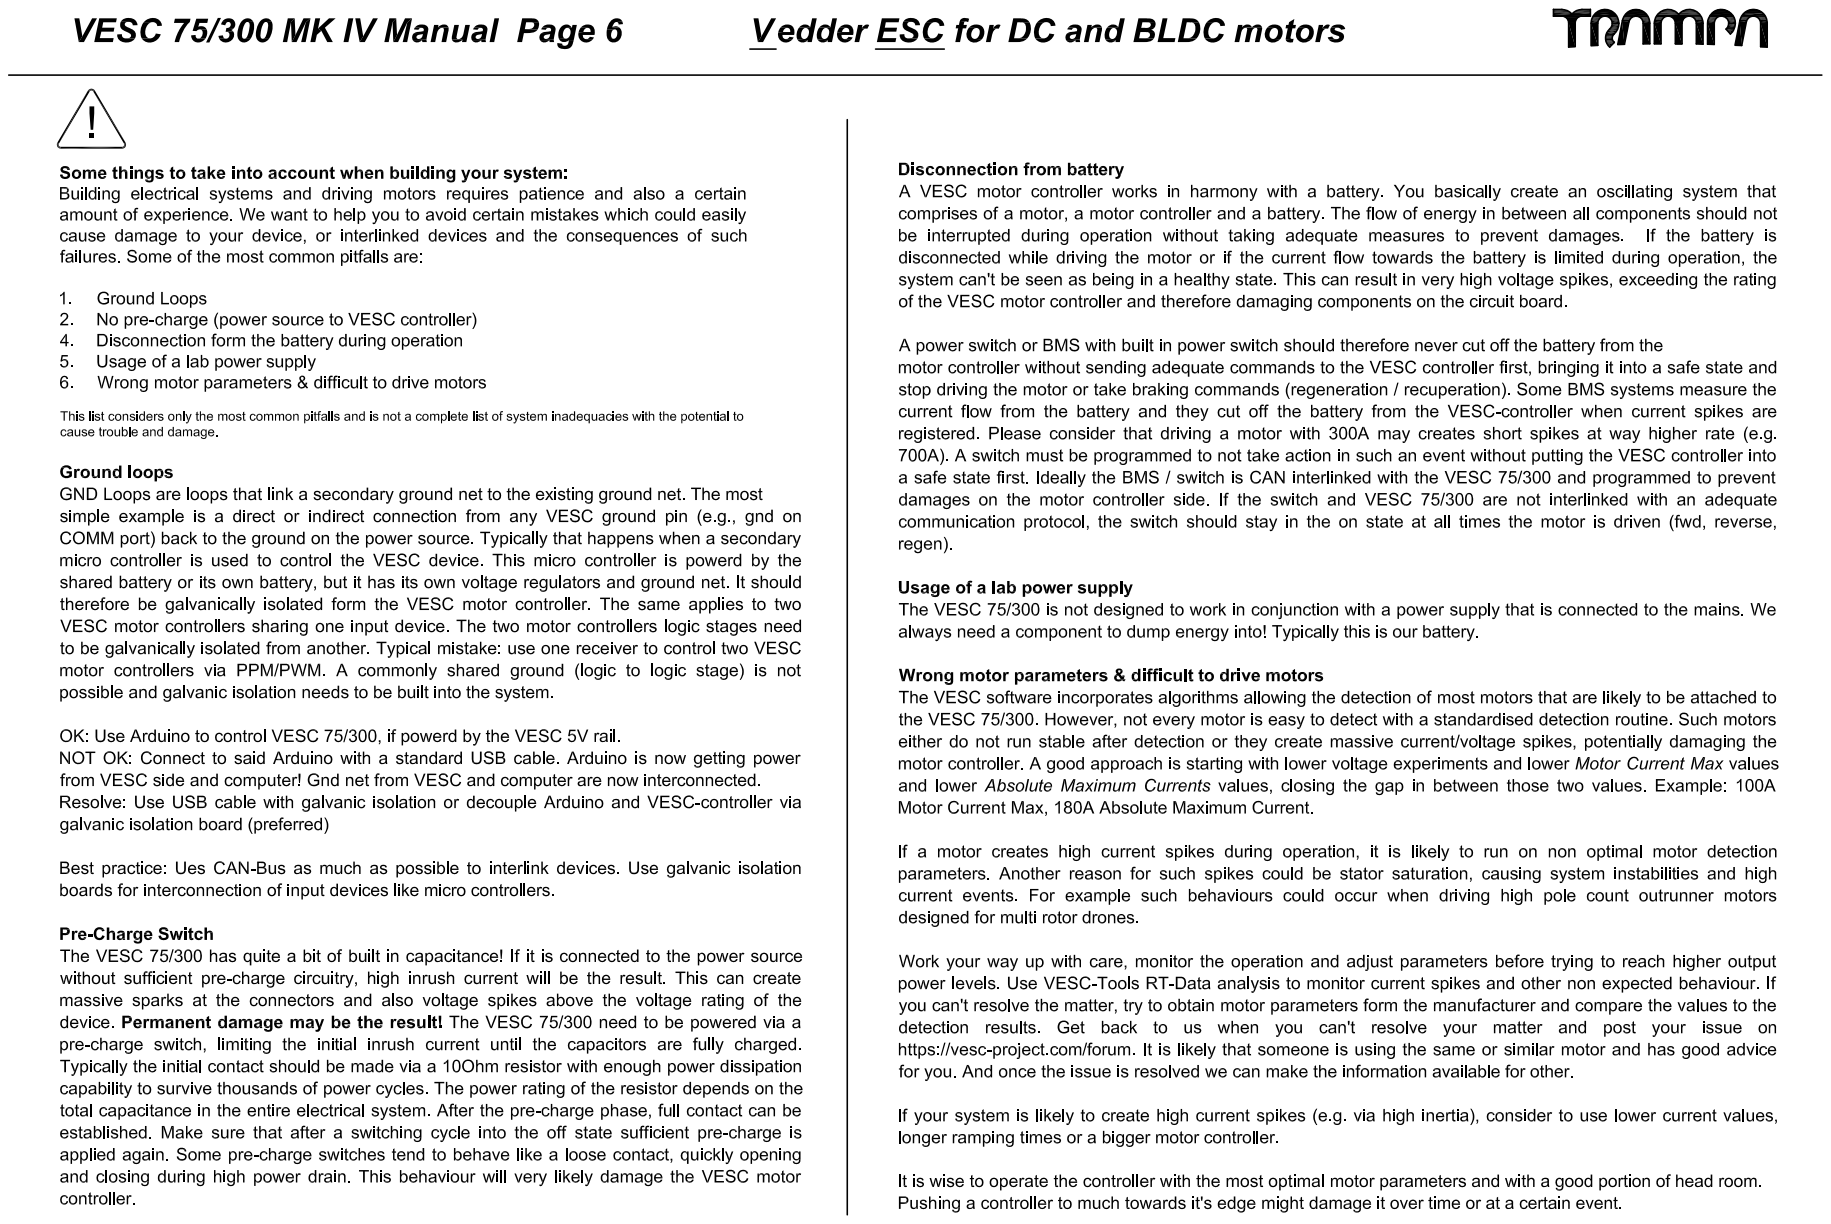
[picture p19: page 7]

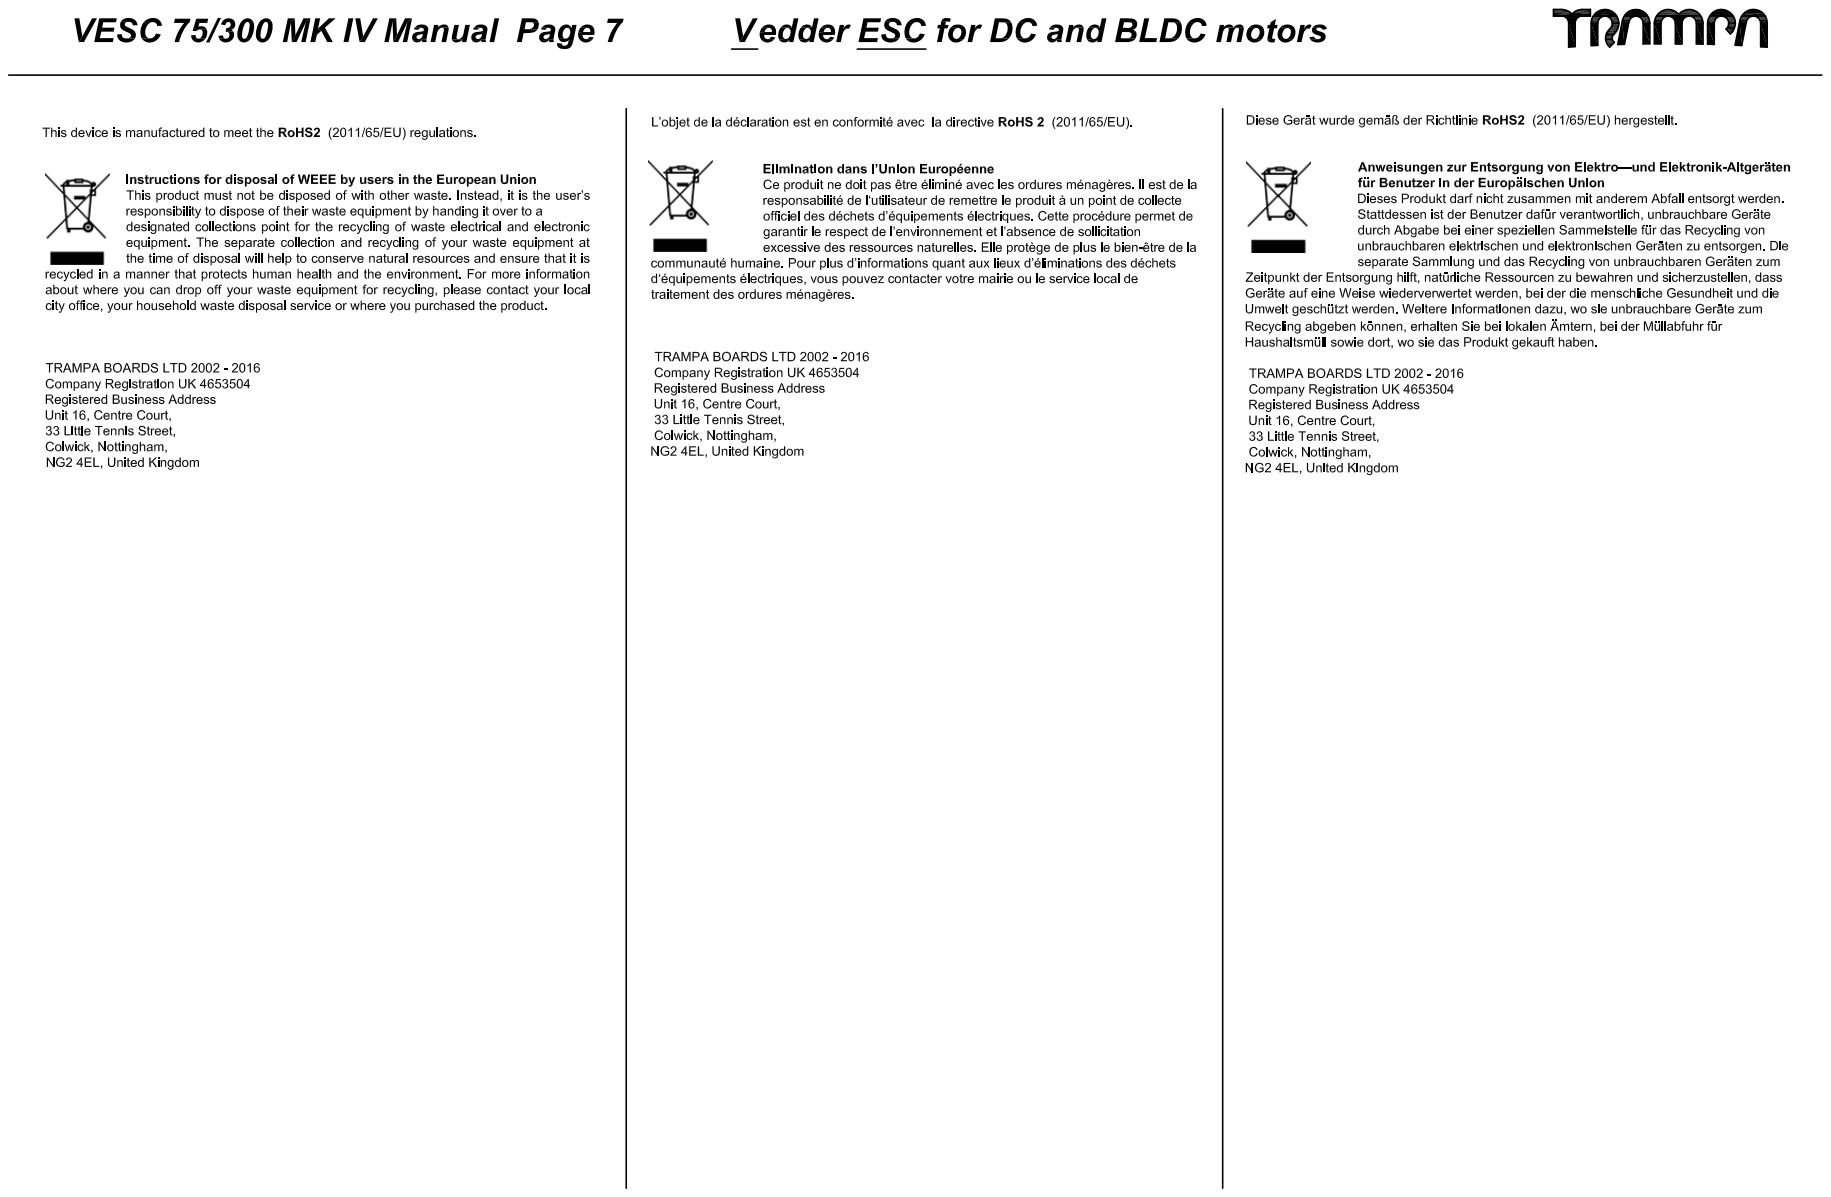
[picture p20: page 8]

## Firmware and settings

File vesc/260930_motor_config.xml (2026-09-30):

<?xml version="1.0" encoding="UTF-8"?>
<MCConfiguration>
    <ConfigVersion>2</ConfigVersion>
    <pwm_mode>1</pwm_mode>
    <comm_mode>0</comm_mode>
    <motor_type>2</motor_type>
    <sensor_mode>0</sensor_mode>
    <l_current_max>250</l_current_max>
    <l_current_min>-250</l_current_min>
    <l_in_current_max>290</l_in_current_max>
    <l_in_current_min>-290</l_in_current_min>
    <l_abs_current_max>290</l_abs_current_max>
    <l_min_erpm>-100000</l_min_erpm>
    <l_max_erpm>100000</l_max_erpm>
    <l_erpm_start>0.8</l_erpm_start>
    <l_max_erpm_fbrake>300</l_max_erpm_fbrake>
    <l_max_erpm_fbrake_cc>1500</l_max_erpm_fbrake_cc>
    <l_min_vin>12</l_min_vin>
    <l_max_vin>72</l_max_vin>
    <l_battery_cut_start>54.4</l_battery_cut_start>
    <l_battery_cut_end>48</l_battery_cut_end>
    <l_slow_abs_current>0</l_slow_abs_current>
    <l_temp_fet_start>85</l_temp_fet_start>
    <l_temp_fet_end>100</l_temp_fet_end>
    <l_temp_motor_start>75</l_temp_motor_start>
    <l_temp_motor_end>85</l_temp_motor_end>
    <l_temp_accel_dec>0.01</l_temp_accel_dec>
    <l_min_duty>0.005</l_min_duty>
    <l_max_duty>0.95</l_max_duty>
    <l_watt_max>1.5e+06</l_watt_max>
    <l_watt_min>-1.5e+06</l_watt_min>
    <l_current_max_scale>1</l_current_max_scale>
    <l_current_min_scale>1</l_current_min_scale>
    <l_duty_start>1</l_duty_start>
    <sl_min_erpm>150</sl_min_erpm>
    <sl_min_erpm_cycle_int_limit>1100</sl_min_erpm_cycle_int_limit>
    <sl_max_fullbreak_current_dir_change>10</sl_max_fullbreak_current_dir_change>
    <sl_cycle_int_limit>62</sl_cycle_int_limit>
    <sl_phase_advance_at_br>0.8</sl_phase_advance_at_br>
    <sl_cycle_int_rpm_br>80000</sl_cycle_int_rpm_br>
    <sl_bemf_coupling_k>600</sl_bemf_coupling_k>
    <hall_table__0>-1</hall_table__0>
    <hall_table__1>1</hall_table__1>
    <hall_table__2>3</hall_table__2>
    <hall_table__3>2</hall_table__3>
    <hall_table__4>5</hall_table__4>
    <hall_table__5>6</hall_table__5>
    <hall_table__6>4</hall_table__6>
    <hall_table__7>-1</hall_table__7>
    <hall_sl_erpm>2000</hall_sl_erpm>
    <foc_current_kp>0.0177969</foc_current_kp>
    <foc_current_ki>4.33851</foc_current_ki>
    <foc_f_zv>30000</foc_f_zv>
    <foc_dt_us>0.12</foc_dt_us>
    <foc_encoder_inverted>0</foc_encoder_inverted>
    <foc_encoder_offset>180</foc_encoder_offset>
    <foc_encoder_ratio>7</foc_encoder_ratio>
    <foc_encoder_sin_gain>1</foc_encoder_sin_gain>
    <foc_encoder_cos_gain>1</foc_encoder_cos_gain>
    <foc_encoder_sin_offset>1.65</foc_encoder_sin_offset>
    <foc_encoder_cos_offset>1.65</foc_encoder_cos_offset>
    <foc_encoder_sincos_filter_constant>0.5</foc_encoder_sincos_filter_constant>
    <foc_sensor_mode>2</foc_sensor_mode>
    <foc_pll_kp>2000</foc_pll_kp>
    <foc_pll_ki>30000</foc_pll_ki>
    <foc_motor_l>1.77969e-05</foc_motor_l>
    <foc_motor_ld_lq_diff>4.71997e-06</foc_motor_ld_lq_diff>
    <foc_motor_r>0.00433851</foc_motor_r>
    <foc_motor_flux_linkage>0.0261091</foc_motor_flux_linkage>
    <foc_observer_gain>1.46695e+06</foc_observer_gain>
    <foc_observer_gain_slow>0.05</foc_observer_gain_slow>
    <foc_observer_offset>-1</foc_observer_offset>
    <foc_duty_dowmramp_kp>10</foc_duty_dowmramp_kp>
    <foc_duty_dowmramp_ki>200</foc_duty_dowmramp_ki>
    <foc_openloop_rpm>150</foc_openloop_rpm>
    <foc_openloop_rpm_low>0</foc_openloop_rpm_low>
    <foc_d_gain_scale_start>0.9</foc_d_gain_scale_start>
    <foc_d_gain_scale_max_mod>0.2</foc_d_gain_scale_max_mod>
    <foc_sl_openloop_hyst>0.1</foc_sl_openloop_hyst>
    <foc_sl_openloop_time_lock>0</foc_sl_openloop_time_lock>
    <foc_sl_openloop_time_ramp>0.1</foc_sl_openloop_time_ramp>
    <foc_sl_openloop_time>0.05</foc_sl_openloop_time>
    <foc_hall_table__0>255</foc_hall_table__0>
    <foc_hall_table__1>65</foc_hall_table__1>
    <foc_hall_table__2>118</foc_hall_table__2>
    <foc_hall_table__3>103</foc_hall_table__3>
    <foc_hall_table__4>199</foc_hall_table__4>
    <foc_hall_table__5>34</foc_hall_table__5>
    <foc_hall_table__6>173</foc_hall_table__6>
    <foc_hall_table__7>255</foc_hall_table__7>
    <foc_hall_interp_erpm>500</foc_hall_interp_erpm>
    <foc_sl_erpm>2000</foc_sl_erpm>
    <foc_sample_v0_v7>0</foc_sample_v0_v7>
    <foc_sample_high_current>0</foc_sample_high_current>
    <foc_sat_comp>0</foc_sat_comp>
    <foc_temp_comp>1</foc_temp_comp>
    <foc_temp_comp_base_temp>15.9</foc_temp_comp_base_temp>
    <foc_current_filter_const>0.1</foc_current_filter_const>
    <foc_cc_decoupling>0</foc_cc_decoupling>
    <foc_observer_type>0</foc_observer_type>
    <foc_hfi_voltage_start>20</foc_hfi_voltage_start>
    <foc_hfi_voltage_run>4</foc_hfi_voltage_run>
    <foc_hfi_voltage_max>10</foc_hfi_voltage_max>
    <foc_sl_erpm_hfi>2000</foc_sl_erpm_hfi>
    <foc_hfi_start_samples>15</foc_hfi_start_samples>
    <foc_hfi_obs_ovr_sec>0.001</foc_hfi_obs_ovr_sec>
    <foc_hfi_samples>1</foc_hfi_samples>
    <foc_offsets_cal_on_boot>1</foc_offsets_cal_on_boot>
    <foc_offsets_current__0>2045.3</foc_offsets_current__0>
    <foc_offsets_current__1>2044.32</foc_offsets_current__1>
    <foc_offsets_current__2>2045.33</foc_offsets_current__2>
    <foc_offsets_voltage__0>-0.0027</foc_offsets_voltage__0>
    <foc_offsets_voltage__1>-0.0097</foc_offsets_voltage__1>
    <foc_offsets_voltage__2>0.0124</foc_offsets_voltage__2>
    <foc_offsets_voltage_undriven__0>0</foc_offsets_voltage_undriven__0>
    <foc_offsets_voltage_undriven__1>0</foc_offsets_voltage_undriven__1>
    <foc_offsets_voltage_undriven__2>0</foc_offsets_voltage_undriven__2>
    <foc_phase_filter_enable>1</foc_phase_filter_enable>
    <foc_phase_filter_max_erpm>4000</foc_phase_filter_max_erpm>
    <foc_mtpa_mode>0</foc_mtpa_mode>
    <foc_fw_current_max>100</foc_fw_current_max>
    <foc_fw_duty_start>0.9</foc_fw_duty_start>
    <foc_fw_q_current_factor>0.02</foc_fw_q_current_factor>
    <foc_fw_ramp_time>0.2</foc_fw_ramp_time>
    <gpd_buffer_notify_left>200</gpd_buffer_notify_left>
    <gpd_buffer_interpol>0</gpd_buffer_interpol>
    <gpd_current_filter_const>0.1</gpd_current_filter_const>
    <gpd_current_kp>0.03</gpd_current_kp>
    <gpd_current_ki>50</gpd_current_ki>
    <sp_pid_loop_rate>5</sp_pid_loop_rate>
    <s_pid_kp>0.004</s_pid_kp>
    <s_pid_ki>0.004</s_pid_ki>
    <s_pid_kd>0.0001</s_pid_kd>
    <s_pid_kd_filter>0.2</s_pid_kd_filter>
    <s_pid_min_erpm>900</s_pid_min_erpm>
    <s_pid_allow_braking>1</s_pid_allow_braking>
    <s_pid_ramp_erpms_s>25000</s_pid_ramp_erpms_s>
    <p_pid_kp>0.025</p_pid_kp>
    <p_pid_ki>0</p_pid_ki>
    <p_pid_kd>0</p_pid_kd>
    <p_pid_offset>0</p_pid_offset>
    <p_pid_kd_proc>0.00035</p_pid_kd_proc>
    <p_pid_kd_filter>0.2</p_pid_kd_filter>
    <p_pid_ang_div>1</p_pid_ang_div>
    <p_pid_gain_dec_angle>0</p_pid_gain_dec_angle>
    <cc_startup_boost_duty>0.01</cc_startup_boost_duty>
    <cc_min_current>0.05</cc_min_current>
    <cc_gain>0.0046</cc_gain>
    <cc_ramp_step_max>0.04</cc_ramp_step_max>
    <m_fault_stop_time_ms>0</m_fault_stop_time_ms>
    <m_duty_ramp_step>0.02</m_duty_ramp_step>
    <m_current_backoff_gain>0.5</m_current_backoff_gain>
    <m_encoder_counts>8192</m_encoder_counts>
    <m_sensor_port_mode>0</m_sensor_port_mode>
    <m_invert_direction>0</m_invert_direction>
    <m_drv8301_oc_mode>0</m_drv8301_oc_mode>
    <m_drv8301_oc_adj>16</m_drv8301_oc_adj>
    <m_bldc_f_sw_min>3000</m_bldc_f_sw_min>
    <m_bldc_f_sw_max>35000</m_bldc_f_sw_max>
    <m_dc_f_sw>25000</m_dc_f_sw>
    <m_ntc_motor_beta>3380</m_ntc_motor_beta>
    <m_out_aux_mode>11</m_out_aux_mode>
    <m_motor_temp_sens_type>2</m_motor_temp_sens_type>
    <m_ptc_motor_coeff>0.61</m_ptc_motor_coeff>
    <m_hall_extra_samples>1</m_hall_extra_samples>
    <si_motor_poles>32</si_motor_poles>
    <si_gear_ratio>1</si_gear_ratio>
    <si_wheel_diameter>0.43</si_wheel_diameter>
    <si_battery_type>0</si_battery_type>
    <si_battery_cells>16</si_battery_cells>
    <si_battery_ah>40</si_battery_ah>
    <si_motor_nl_current>1</si_motor_nl_current>
    <motor_brand>Unnamed</motor_brand>
    <motor_model>Not Specified</motor_model>
    <motor_weight>0</motor_weight>
    <motor_sensor_type>0</motor_sensor_type>
    <motor_description>&lt;!DOCTYPE HTML PUBLIC &quot;-//W3C//DTD HTML 4.0//EN&quot; &quot;http://www.w3.org/TR/REC-html40/strict.dtd&quot;&gt;
&lt;html&gt;&lt;head&gt;&lt;meta name=&quot;qrichtext&quot; content=&quot;1&quot; /&gt;&lt;style type=&quot;text/css&quot;&gt;
p, li { white-space: pre-wrap; }
&lt;/style&gt;&lt;/head&gt;&lt;body style=&quot; font-family:'Roboto'; font-size:12pt; font-weight:400; font-style:normal;&quot;&gt;
&lt;p style=&quot; margin-top:0px; margin-bottom:0px; margin-left:0px; margin-right:0px; -qt-block-indent:0; text-indent:0px;&quot;&gt;A motor description can be edited here.&lt;/p&gt;&lt;/body&gt;&lt;/html&gt;</motor_description>
    <motor_quality_bearings>0</motor_quality_bearings>
    <motor_quality_magnets>0</motor_quality_magnets>
    <motor_quality_construction>0</motor_quality_construction>
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

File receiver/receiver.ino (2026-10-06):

/* RECEIVER
 * receives target pull value from lora link
 * sends acknowlegement on lora with current parameters
 * writes target pull with PWM signal to vesc
 * reads current parameters (tachometer, battery %, motor temp) with UART from vesc, based on (https://github.com/SolidGeek/VescUart/)
 * A relay on IO12 switches the VESC cooling fan. The receiver switches it on by itself
 * while a pull state is active and off again after FAN_RUN_ON_MS without pull [WINCH-07].
 * (The emergency line cutter was removed [WINCH-05].)
 */

//vesc battery number of cells
static int numberOfCells = 16;

#include "LiPoCheck.h"    //to calculate battery % based on cell Voltage

#include <Pangodream_18650_CL.h>
#include <SPI.h>
#include <LoRa.h>

// Include the correct display library for a connection via I2C using Wire include
#include <Wire.h>  // Only needed for Arduino 1.6.5 and earlier
#include "SSD1306Wire.h" // legacy include: `#include "SSD1306.h"

SSD1306Wire display(0x3c, SDA, SCL);   // ADDRESS, SDA, SCL - SDA and SCL usually populate automatically based on your board's pins_arduino.h e.g. https://github.com/esp8266/Arduino/blob/master/variants/nodemcu/pins_arduino.h

#define SCK     5    // GPIO5  -- SX1278's SCK
#define MISO    19   // GPIO19 -- SX1278's MISnO
#define MOSI    27   // GPIO27 -- SX1278's MOSI
#define SS      18   // GPIO18 -- SX1278's CS
#define RST     23   // GPIO23 -- SX1278's RESET on TTGO LoRa32 V2.1_1.6 (was 14, which is also VESC_RX: LoRa.begin() turned the UART RX pin into an output) [WINCH-15/16]
#define DI0     26   // GPIO26 -- SX1278's IRQ(Interrupt Request)
#define BAND  868E6  //frequency in Hz (433E6, 868E6, 915E6) 

int rssi = 0;
float snr = 0;
String packSize = "--";
String packet ;

#include <rom/rtc.h>
#include "Arduino.h"
#include <Button2.h>

// battery measurement
//#define CONV_FACTOR 1.7
//#define READS 20
Pangodream_18650_CL BL(35); // pin 34 old / 35 new v2.1 hw

// Relay for the VESC cooling fan [WINCH-07]
int relayPin = 12; //Connect Relay Red Cable to 5V, Black Cable to GND and White Cable / Signal to Pin 12
// Relay module polarity: true = IO12 HIGH switches the fan on (active-high module),
// false = IO12 LOW switches the fan on (active-low module). Check on the bench that the fan
// physically runs when the OLED shows "Fan ON" (known bug in WINCH-07).
#define RELAY_ACTIVE_HIGH  true
// Fan run-on after the last pull state (state >= 1), in ms. Lets the VESC cool down and
// avoids switching the fan on and off during step tows.
#define FAN_RUN_ON_MS  120000UL
bool relay = false;                     // fan on/off, decided by the receiver only
unsigned long lastPullStateMillis = 0;  // last time a pull state (currentState >= 1) was active
bool pullStateSeen = false;             // no run-on after power-up in brake

//Using VescUart library to read from Vesc (https://github.com/SolidGeek/VescUart/)
#include <VescUart.h>
#define VESC_RX  14    //connect to TX on Vesc
#define VESC_TX  2    //connect to RX on Vesc
VescUart vescUART;

// PWM signal to vesc
#define PWM_PIN_OUT  13 //Define Digital PIN
#define PWM_TIME_0      950.0    //PWM time in ms for 0% , PWM below will be ignored!! need XXX.0!!!
#define PWM_TIME_100    2000.0   //PWM time in ms for 100%, PWM above will be ignored!!

static int loopStep = 0;
static uint8_t activeTxId = 0;

/*
* Copyright 2015 - 2017 Andreas Chaitidis Andreas.Chaitidis@gmail.com
* This program is free software : you can redistribute it and / or modify
* it under the terms of the GNU General Public License as published by
* the Free Software Foundation, either version 3 of the License, or
* (at your option) any later version.
* This program is distributed in the hope that it will be useful,
* but WITHOUT ANY WARRANTY; without even the implied warranty of
* MERCHANTABILITY or FITNESS FOR A PARTICULAR PURPOSE.See the
* GNU General Public License for more details.
* You should have received a copy of the GNU General Public License
* along with this program.If not, see <http://www.gnu.org/licenses/>.
*/

//sent by transmitter
struct LoraTxMessage {
   uint8_t id : 4;              // unique id 1 - 15, id 0 is admin!
   int8_t currentState : 4;    // -2 --> -2 = hard brake -1 = soft brake, 0 = no pull / no brake, 1 = default pull (2kg), 2 = pre pull, 3 = take off pull, 4 = full pull, 5 = extra strong pull
   int8_t pullValue;           // target pull value,  -127 - 0 --> 5 brake, 0 - 127 --> pull
   int8_t pullValueBackup;     // to avoid transmission issues, TODO remove, CRC is enough??
   // [WINCH-05/07] servo and relay fields removed: 3 bytes instead of 5. Transmitter and
   // receiver must be flashed together; packets of the old size are ignored.
};
//send by receiver (acknowledgement)
struct LoraRxMessage {
   int8_t pullValue;           // currently active pull value,  -127 - 0 --> 5 brake, 0 - 127 --> pull
   uint8_t tachometer;          // *10 --> in meter
   uint8_t dutyCycleNow;
   uint8_t vescBatteryOrTempMotor : 1 ;  // 0 ==> vescTempMotor , 1 ==> vescBatteryPercentage
   uint8_t vescBatteryOrTempMotorValue  : 7 ;   //0 - 127
};

struct LoraTxMessage loraTxMessage;
struct LoraRxMessage loraRxMessage;

// Packets are matched by size: both sketches must have the same sizes [WINCH-05/07]
static_assert(sizeof(LoraTxMessage) == 3, "LoraTxMessage must be 3 bytes, same as in transmitter.ino");
static_assert(sizeof(LoraRxMessage) == 4, "LoraRxMessage must be 4 bytes, same as in transmitter.ino");

int smoothStep = 0;    // used to smooth pull changes
int hardBrake = -20;  //in kg
int softBrake = -8;  //in kg
int defaultPull = 8;  //in kg
// The pull states (myMaxPull, scales) live in the transmitter only. The receiver uses the
// three values above for failsafe and autostop. Unused copies removed 2026-10-03 [WINCH-15].

int currentId = 0;
int currentState = -1;
// pull value send to VESC --> default soft brake
// defined as int to allow smooth changes without overrun
int currentPull = softBrake;     // active range -127 to 127
int8_t targetPullValue = 0;    // received from lora transmitter or rewinding winch mode

uint8_t vescBattery = 0;
uint8_t vescTempMotor = 0;
bool vescUartOk = false;   // result of the last UART read, shown on the OLED [WINCH-16]

unsigned long lastTxLoraMessageMillis = 0;
unsigned long previousTxLoraMessageMillis = 0;
unsigned long lastRxLoraMessageMillis = 0;
unsigned long previousRxLoraMessageMillis = 0;
uint32_t  pwmReadTimeValue = 0;
uint32_t  pwmWriteTimeValue = 0;
unsigned long lastWritePWMMillis = 0;
unsigned int loraErrorCount = 0;
unsigned long loraErrorMillis = 0;


void pulseOut(int pin, int us)
{
   digitalWrite(pin, HIGH);
   us = max(us - 20, 1);  //biase caused by digital write/read
   delayMicroseconds(us);
   digitalWrite(pin, LOW);
}

void setup() {
  Serial.begin(115200);

  //Setup UART port for Vesc communication
  Serial1.begin(115200, SERIAL_8N1, VESC_RX, VESC_TX);
  vescUART.setSerialPort(&Serial1);
  //vescUART.setDebugPort(&Serial);

  // Setup Relay, fan off at power-up
  pinMode(relayPin, OUTPUT);
  digitalWrite(relayPin, RELAY_ACTIVE_HIGH ? LOW : HIGH);

  //lora init
  SPI.begin(SCK,MISO,MOSI,SS);
  LoRa.setPins(SS,RST,DI0);
  if (!LoRa.begin(868E6)) {
    Serial.println("Starting LoRa failed!");
    while (1);
  }
  LoRa.setTxPower(20, PA_OUTPUT_PA_BOOST_PIN);
  //LoRa.setSpreadingFactor(10);   // default is 7, 6 - 12
  LoRa.enableCrc();
  //LoRa.setSignalBandwidth(500E3);   //signalBandwidth - signal bandwidth in Hz, defaults to 125E3. Supported values are 7.8E3, 10.4E3, 15.6E3, 20.8E3, 31.25E3, 41.7E3, 62.5E3, 125E3, 250E3, and 500E3.

  // display init
  display.init();
  display.flipScreenVertically();  

  //PWM Pins
  //pinMode(PWM_PIN_IN, INPUT);
  pinMode(PWM_PIN_OUT, OUTPUT);
  
  display.clear();
  display.setTextAlignment(TEXT_ALIGN_LEFT);
  display.setFont(ArialMT_Plain_10);
  Serial.printf("Starting Receiver \n");
  display.drawString(0, 0, "Starting Receiver");
}

void loop() {

 loopStep++;
 // TODO activate rewinding winch mode here
 if (true) {
    // screen
    if (loopStep % 10 == 0) {
      display.clear();
      display.setTextAlignment(TEXT_ALIGN_LEFT);
      display.setFont(ArialMT_Plain_10);  //10, 16, 24
      display.drawString(0, 0, currentId + String("-RX: (") + BL.getBatteryChargeLevel() + "%, " + rssi + "dBm, " + snr + ")");
      display.setFont(ArialMT_Plain_24);  //10, 16, 24
      if (currentState > 0){
          display.drawString(0, 11, String("P ") + currentState + ": (" + currentPull + "kg)");  
      } else {
          display.drawString(0, 11, String("B ") + currentState + ": (" + currentPull + "kg)");    
      }
      display.setFont(ArialMT_Plain_10);  //10, 16, 24
      //display.drawString(0, 36, String("Error / Uptime{min}: ") + loraErrorCount + " / " + millis()/60000);
      // display.drawString(0, 36, String("B: ") + vescBattery + "%, M: " + vescTempMotor + "C");
      if (relay == true && currentState >= 1) {
        display.drawString(0, 36, String("Fan ON"));
      } else if (relay == true) {
        // run-on: show remaining seconds
        unsigned long fanOnSinceMs = millis() - lastPullStateMillis;
        unsigned long fanRemainingS = fanOnSinceMs < FAN_RUN_ON_MS ? (FAN_RUN_ON_MS - fanOnSinceMs) / 1000 : 0;
        display.drawString(0, 36, String("Fan ON (off in ") + fanRemainingS + " s)");
      } else {
        display.drawString(0, 36, String("Fan OFF"));
      }
      // display.drawString(0, 48, String("Last TX / RX: ") + lastTxLoraMessageMillis/100 + " / " + lastRxLoraMessageMillis/100);
      // UART telemetry: raw tachometer counts and duty cycle as read from the VESC [WINCH-16]
      // e.g. "Tac 15914 D 12% ok", "ERR" = last UART read failed (values are then the last good ones)
      display.drawString(0, 48, String("Tac ") + vescUART.data.tachometer + " D "
                         + (int)abs(vescUART.data.dutyCycleNow * 100) + "% " + (vescUartOk ? "ok" : "ERR"));
      display.display();
    }
    
    // LoRa data available?
    // packet from transmitter
    if (LoRa.parsePacket() == sizeof(loraTxMessage) ) {
          LoRa.readBytes((uint8_t *)&loraTxMessage, sizeof(loraTxMessage));
          // allow only one ID to control the winch at a given time
          // after 5 seconds without a message, a new id is allowed
          if (millis() > lastTxLoraMessageMillis + 5000){
            activeTxId = loraTxMessage.id;
          }
          // The admin id 0 can always take over
          if (loraTxMessage.id == 0){
            activeTxId = loraTxMessage.id;
          }
          if (loraTxMessage.id == activeTxId && loraTxMessage.pullValue == loraTxMessage.pullValueBackup) {
              targetPullValue = loraTxMessage.pullValue;
              currentId = loraTxMessage.id;
              currentState = loraTxMessage.currentState;
              previousTxLoraMessageMillis = lastTxLoraMessageMillis;  // remember time of previous paket
              lastTxLoraMessageMillis = millis();
              rssi = LoRa.packetRssi();
              snr = LoRa.packetSnr();

              // Serial.printf("Value received: %d, RSSI: %d: , SNR: %d \n", loraTxMessage.pullValue, rssi, snr);
              
              // send ackn after receiving a value
              delay(10);
              loraRxMessage.pullValue = currentPull;
              loraRxMessage.tachometer = abs(vescUART.data.tachometer)/1000;     // %100 --> in m, %10 --> to use only one byte for up to 2550m line lenght
              loraRxMessage.dutyCycleNow = abs(vescUART.data.dutyCycleNow * 100);     //in %
              // alternate vescBatteryPercentage and vescTempMotor value on lora link to reduce packet size
              if (loraRxMessage.vescBatteryOrTempMotor == 0){
                loraRxMessage.vescBatteryOrTempMotor = 1;
                loraRxMessage.vescBatteryOrTempMotorValue = vescBattery;
              } else {
                loraRxMessage.vescBatteryOrTempMotor = 0;
                loraRxMessage.vescBatteryOrTempMotorValue = vescTempMotor;
              }
              if (LoRa.beginPacket()) {
                  LoRa.write((uint8_t*)&loraRxMessage, sizeof(loraRxMessage));
                  LoRa.endPacket();
                  // Serial.printf("sending Ackn currentPull %d: \n", currentPull);
                  lastRxLoraMessageMillis = millis();  
              } else {
                  Serial.println("Lora send busy");
              }
              
          } else {
            Serial.println("Wrong transmitter id or backup Value:");
            Serial.println(loraTxMessage.id);
            Serial.println(loraTxMessage.pullValue);
            Serial.println(loraTxMessage.pullValueBackup);
          }
     }
  
      // if no lora message for more then 1,5s --> show error on screen + acustic
      if (millis() > lastTxLoraMessageMillis + 1500 ) {
            //TODO acustic information
            //TODO  red display
            display.clear();
            display.display();
            // log connection error
           if (millis() > loraErrorMillis + 5000) {
                loraErrorMillis = millis();
                loraErrorCount = loraErrorCount + 1;
           }
      }
      // Failsafe only when pull was active
      if (currentState >= 1) {
            // no packet for 1,5s --> failsave
            if (millis() > lastTxLoraMessageMillis + 1500 ) {
                 // A) keep default pull if connection issue during pull for up to 20 seconds
                 if (millis() < lastTxLoraMessageMillis + 20000) {
                    targetPullValue = defaultPull;   // default pull
                    currentState = 1;
                 } else {
                 // B) go to soft brake afterwards
                    targetPullValue = softBrake;     // soft brake
                    currentState = -1;
                 }
            }
      }
 } else {
      // rewinding winch mode
      // screen
      if (loopStep % 10 == 0) {
        display.clear();
        display.setTextAlignment(TEXT_ALIGN_LEFT);
        display.setFont(ArialMT_Plain_10);  //10, 16, 24
        display.drawString(0, 0, "rewinding winch mode");
        display.setFont(ArialMT_Plain_24);  //10, 16, 24
        display.drawString(0, 14, String(targetPullValue) + "/" + currentPull + "kg");
        display.display();
      }

      // small pull value on pull out
      // higher pull value on pull in
      if (vescUART.data.dutyCycleNow > 0.02){
        targetPullValue = 10;
      } else if (vescUART.data.dutyCycleNow < -0.02){
        targetPullValue = 17;
      } else {
        targetPullValue = -5; // no line movement --> soft brake
      }
      // ??? TODO higher pull value on fast pull out to avoid drum overshoot on line disconection ???
      
 }  // end rewind winch mode

      // auto line stop
      // (smooth to avoid line issues on main winch with rewinding winch)
      // tachometer > 2 --> avoid autostop when no tachometer values are read from uart (--> 0)
      if (vescUART.data.tachometer > 2 && vescUART.data.tachometer < 40) {
          if (targetPullValue > defaultPull){
              targetPullValue = defaultPull;
          }
          if (vescUART.data.tachometer < 20) {
              targetPullValue = softBrake;
          }
          if (vescUART.data.tachometer < 10) {
              targetPullValue = hardBrake;
          }
          Serial.println("Autostop active, target pull value:");
          Serial.println(targetPullValue);
      }
 
      // smooth changes
      // if brake --> immediately active
      if (targetPullValue < 0 ){
          currentPull = targetPullValue;
      } else {   
          // change rate e.g. max. 50 kg / second
          //reduce pull
          if (currentPull > targetPullValue) {
              smoothStep = 90 * (millis() - lastWritePWMMillis) / 1000;
              if ((currentPull - smoothStep) > targetPullValue)   //avoid overshooting
                  currentPull = currentPull - smoothStep;
              else
                  currentPull = targetPullValue;
          //increase pull
          } else if (currentPull < targetPullValue) {
              smoothStep = 65 * (millis() - lastWritePWMMillis) / 1000;
              if ((currentPull + smoothStep) < targetPullValue)   //avoid overshooting
                  currentPull = currentPull + smoothStep;
              else
                  currentPull = targetPullValue;
          }
          //Serial.println(currentPull);
          //avoid overrun
          if (currentPull < -127)
            currentPull = -127;
          if (currentPull > 127)
            currentPull = 127;
      }
      
      delay(10);
      //calculate PWM time for VESC
      // write PWM signal to VESC
      pwmWriteTimeValue = (currentPull + 127) * (PWM_TIME_100 - PWM_TIME_0) / 254 + PWM_TIME_0;     
      pulseOut(PWM_PIN_OUT, pwmWriteTimeValue);
      lastWritePWMMillis = millis();
      delay(10);    //RC PWM usually has a signal every 20ms (50 Hz)

  // Relay for the VESC cooling fan [WINCH-07]
  // ON while a pull state is active (including failsafe default pull),
  // OFF after FAN_RUN_ON_MS without any pull state.
     if (currentState >= 1) {
       lastPullStateMillis = millis();
       pullStateSeen = true;
     }
     relay = pullStateSeen && (millis() - lastPullStateMillis < FAN_RUN_ON_MS);
     if (relay) {
       digitalWrite(relayPin, RELAY_ACTIVE_HIGH ? HIGH : LOW); // fan on
     } else {
       digitalWrite(relayPin, RELAY_ACTIVE_HIGH ? LOW : HIGH); // fan off
     }

      //read actual Vesc values from uart
      if (loopStep % 20 == 0) {
        vescUartOk = vescUART.getVescValues();
        if (vescUartOk) {
            vescBattery = CapCheckPerc(vescUART.data.inpVoltage, numberOfCells);    // vesc battery in %
            vescTempMotor = vescUART.data.tempMotor;                                // motor temp in C
            // UART diagnosis on the USB serial monitor (115200 baud) [WINCH-16]
            Serial.printf("VESC ok: %.1f V, tacho %ld, duty %.2f, motor %.0f C\n",
                          vescUART.data.inpVoltage, (long)vescUART.data.tachometer,
                          vescUART.data.dutyCycleNow, vescUART.data.tempMotor);
            //SerialPrint(measuredVescVal, &DEBUGSERIAL);
            /*
            Serial.println(vescUART.data.tachometer);
            Serial.println(vescUART.data.inpVoltage);
            Serial.println(vescUART.data.dutyCycleNow);            
            Serial.println(vescUART.data.tempMotor);
            Serial.println(vescUART.data.tempMosfet);
            vescUART.printVescValues();
            */
          }
        else
          {
            //TODO send notification to lora
            //measuredVescVal.tachometer = 0;
            Serial.println("Failed to get data from VESC!");   // UART diagnosis [WINCH-16]
          }
      }
}

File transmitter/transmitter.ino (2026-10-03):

/* TRANSMITTER
 * sends current state (pull value)
 * receives acknowlegement with current parameters
 * communication is locked to a specific transmitter for 5 seconds after his last message
 * admin ID 0 can always take over communication
 *
 * [WINCH-05/07] The third button, the line cutter (servo) and the manual relay (fan) control
 * were removed. The receiver now switches the cooling fan by itself.
 *
 * +++ Almost done, needs testing +++ Adding support to connect a Liligo T-Display S-3
 * as a Monitor via ESP-NOW Protocol (over Wifi) and as an option to control Relay,
 * Servo and maxPull Settings via Transmitter. Monitor acts as a transmitter extension.
 *
 * [WINCH-04] The monitor has been retired. All ESP-NOW monitor code is commented out
 * in four blocks marked "[WINCH-04]". To re-enable it, delete the comment start and
 * comment end lines of all four blocks. The blocks still reference the removed servo and
 * relay variables, so those lines would have to be removed as well.
 */

static int myID = 3;    // set to your desired transmitter id, "0" is for admin 1 - 15 is for additional transmitters [unique number from 1 - 15]
// UPDATE the maxPull Variable can now be updated with a potentionmeter on the Lilygo T-Display Monitor (disabled, see [WINCH-04])
static int myMaxPull = 95;  // 0 - 127 [kg], must be scaled with VESC ppm settings

#include <Pangodream_18650_CL.h>
#include <SPI.h>
#include <LoRa.h>

// Include display library for a connection via I2C using Wire include for the onboard OLED Display
#include <Wire.h>  // Only needed for Arduino 1.6.5 and earlier
#include "SSD1306Wire.h" // legacy include: `#include "SSD1306.h"`

// Initialize the onboard OLED display using Wire library
SSD1306Wire display(0x3c, SDA, SCL);   // ADDRESS, SDA, SCL - SDA and SCL usually populate automatically based on your board's pins_arduino.h e.g. https://github.com/esp8266/Arduino/blob/master/variants/nodemcu/pins_arduino.h

#define SCK     5    // GPIO5  -- SX1278's SCK
#define MISO    19   // GPIO19 -- SX1278's MISnO
#define MOSI    27   // GPIO27 -- SX1278's MOSI
#define SS      18   // GPIO18 -- SX1278's CS
#define RST     23   // GPIO23 -- SX1278's RESET on TTGO LoRa32 V2.1_1.6 (was 14) [WINCH-15/16]
#define DI0     26   // GPIO26 -- SX1278's IRQ(Interrupt Request)
#define BAND  868E6  //frequency in Hz (433E6, 868E6, 915E6)

int rssi = 0;
float snr = 0;
String packSize = "--";
String packet ;

#include <rom/rtc.h>

#include "Arduino.h"
#include <Button2.h>

/*
*  ESP-NOW Communication between Transmitter and a Monitor
*  The Monitor could be a Liligo T-Display S-3
*  Code basis for ESP-NOW Communication by Rui Santos
*  Complete project details at https://RandomNerdTutorials.com/esp-now-esp32-arduino-ide/
*  Permission is hereby granted, free of charge, to any person obtaining a copy
*  of this software and associated documentation files.
*  The above copyright notice and this permission notice shall be included in all
*  copies or substantial portions of the Software.
*/
// [WINCH-04] ESP-NOW monitor disabled (block 1 of 4: includes + MAC)
/*
#include <esp_now.h>
#include <WiFi.h>
// Replace with your ESP-Now Receiver/Monitor MAC Address:
uint8_t broadcastAddress[] = {0xDC, 0xDA, 0x0C, 0x5A, 0x59, 0x58};
*/

// battery measurement
//#define CONV_FACTOR 1.7
//#define READS 20
Pangodream_18650_CL BL(35); // pin 34 old / 35 new v2.1 hw

// Buttons for state machine control
#define BUTTON_UP  15 // up
#define BUTTON_DOWN  12 // down

Button2 btnUp = Button2(BUTTON_UP);
Button2 btnDown = Button2(BUTTON_DOWN);
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

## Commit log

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2022-10-11 updated display code
    I could not make Robert Zach's code work with the ESP32 Paxcounter Board that is linked in the readme.md, so I dug into it and found a solution. updated the code accordingly. I used an updated SSD130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
2022-10-11 updated display code and comments
    I could not make Robert Zach's code work with the ESP32 Paxcounter Board that is linked in the readme.md, so I dug into it and found a solution. updated the code accordingly: I used an updated SSD130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
2023-02-23 16S10P Lithium Ion Battery (60V)
    Photo shows the 16S10P Lithium Ion Battery made with LiitoKala Lii-40A 21700 4000mah, 40A 3.7V 10C discharge Cells. Spot welded and added copper busbar.
    The left side shows the ~60 V (59,2V) output with XT90 connectors (all three in parallel, to connect with VESC). The right side shows 2x XT60 connectors which splits the battery into two charging por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
2023-03-27 stainless steel drum plate
    two of these plates are mounted to the sides of the motor to construct the drum/spool
    [230326_trommelscheibe.dxf]
2023-05-25 Update README.md
    added description how to use the ESP32 with Arduino IDE
2023-09-14 Create transmitter_plus_servo.ino
    Trying my first own code:
    adding a tripleClick Function to trigger a Servo that will enable a LineCutter on the winch
2023-09-14 Create transmitter_plus_servo
    trying to add a servo for triggering a line cutter
2023-12-26 Update monitor.ino
    small correction for display functionality.
    [monitor.ino]
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2024-01-05 Create transmitter-with-relay-and-servo.ino
    Trying to add
    - Servo Control - Servo will trigger a line cutter in case of emergency. Required by DHV rules
    - Relay Control - upon successful self launch I would want to switch of the loud and noisy fan and warning light on the winch
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2024-01-08 Update transmitter-with-relay-and-servo.ino
    removed a small error
    code works so far, button presses are registered and sent to serial monitor! Yay
2024-01-10 Update transmitter-with-relay-and-servo.ino
    adding function to read status of Servo and Relay.
    Needs some refinement and better readability, though, not ready for production yet.
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2024-01-11 Update monitor-with-external-tft.ino
    corrected minor error.
    [monitor-with-external-tft.ino]
2024-01-11 Update transmitter-with-relay-and-servo.ino
    I have accidentally overwritten this file with the "monitor" code. Reverting back to the original, correct version.
2024-01-11 Update receiver.ino
    started to add support for Relay and Servo - not yet done.
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2024-01-15 Update receiver.ino
    Added support for a Servo.
    Servo is attached to Pin 15.
    The Servo rotates 90 degrees when a button on the transmitter is "long pressed" (longer than a second)
    The servo will trigger an emergency line cutter, as required by DHV regulations
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2024-01-17 Add files via upload
    DXF Files of stainless steel plates, planning to put the winch on a bike trailer
    [bodenplatte.dxf, windenhalterung.dxf]
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2024-01-17 Delete transmitter/transmitter-with-relay-and-servo.ino
    will move code to main file transmitter.ino.
    Need to learn to work with branches :-)
2024-01-17 Update transmitter.ino
    Added support for a third button to control a Relay and a Servo.
    The Relay can turn the VESC Cooling Fan and Warning Light (DHV Regulations) on and off
    The Servo can trigger an Emergency Line Cutter (DHV Regulations)
2024-01-17 Update receiver.ino
    Added Support for a Relay and a Servo
    The Relay controls the VESC Cooling Fan and a Warning Light (DHV Regulations)
    The Servo triggers an Emergency Line Cutter
2024-01-17 Update README.md
    added description for third button on Transmitter, Relay and Servo connection and control.
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2024-02-16 Update transmitter.ino
    there was an error in the code - one section was copied twice.
    [transmitter.ino]
2024-03-12 corrected Servo Pin
    corrected Servo Pin
2024-03-21 corrected file name endings
    [monitor_and_maxpull-control.cpp]
2024-03-21 updated readme to include description of monitor and the switch to Visual Studio Code
2024-03-21 corrected tiny error, added comment
    [monitor_and_maxpull-control.cpp]
2024-04-04 correct conflicting servo pin
    correct conflicting servo pin
    [receiver.ino]
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2024-06-01 added my motor and app config
    added my motor (12kW) and app config. every motor is different.
    [240601_app_config.xml, 240601_motor_config.xml]
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2024-06-30 corrected flange bearing spec
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2025-07-11 rotary setup
    This is a video of the rotary setup for the bike trailer - it was later replaced with a new, stationary frame and an azimuth system
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2026-09-28 Add Trampa VESC 75/300 specs and manual (WINCH-10)
    - vesc/readme.md: new section on the controller used on this winch,
    winch-relevant notes (67.2V limit vs. regenerative braking, cooling,
    1A aux output budget) and full manufacturer specs
    - vesc/VESC-75-300-MKIV-MANUAL.pdf: manufacturer manual
    - features: WINCH-10 marked done; open question on MKIV vs. R3 revision
2026-09-28 WINCH-02: Sync transmitter with Etienne's local version (2025-08-24)
    Replace transmitter_with-monitor-support.cpp with the local version that
    is most likely flashed on the handheld. Based on 8433fe0 (2024-03-21).
    Differences to previous repo version (a57a14f):
    - myID 8 -> 3
    - myMaxPull 85 -> 95 (safety-relevant: pull states 2-5 increase,
    e.g. prePull 15 -> 17 kg; matches pilot take-off weight)
    - removed loraConnect field/logic (ESP-NOW monitor struct changed)
    - ESP-NOW send interval loopStep % 20 -> % 50
    - ESP-NOW monitor MAC DC:DA:0C:58:FE:B8 -> DC:DA:0C:5A:59:58
    - comment changes
    LoRa structs unchanged. Receiver unchanged (local files identical).
    Not compiled yet.
    Docs: README and CLA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
2026-09-28 WINCH-02: Mark as done
    Compile check and on-device verification (OLED shows ID 3) deferred by
    Etienne; compile check moves to WINCH-03.
2026-09-28 WINCH-01: Mark as done
    README rewind rule (max. state 2) approved by Etienne. Log notes the
    prePull value update to ~17 kg from WINCH-02.
2026-09-28 WINCH-04: Archive cockpit monitor to old/, comment out ESP-NOW in transmitter
    - monitor-LoRa/, monitor-ESP-NOW/, doc/t-display-s3-pinout.jpg -> old/
    - new old/README.md explaining the archive
    - transmitter.ino: ESP-NOW monitor code commented out in four blocks
    marked [WINCH-04] (kept, not deleted). Active code otherwise unchanged
    (checked by comparing comment-stripped code). No change to pull/brake
    values, failsafe or LoRa structs.
    - README, parts-list, CLAUDE.md: monitor sections removed / updated
    Not compiled, not flashed yet.
    [mac-address.cpp, monitor-with-external-tft.ino, monitor.ino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]
2026-09-28 WINCH-07: Add known bug - fan does not run although OLED shows ON
    Reported by Etienne. OLED only reflects the relay variable, so the fault
    is most likely between IO12 and the fan (relay polarity, 3.3 V trigger
    level, supply, wiring). Diagnosis checklist and bench test step added.
2026-09-28 WINCH-16: Track line length / duty cycle stuck at 0 (UART telemetry)
    New P0 feature, placed before WINCH-08 (autostop verification needs a
    trustworthy tachometer). First findings from Etienne: UART works
    (battery 45 % shown), tachometer stopped counting ~2 days ago, sensor
    cable unplugged after a VESC error, autostop seems to still work.
    Diagnosis steps and open questions recorded; debugging postponed.
    WINCH-08 now depends on WINCH-16.
2026-09-28 README: Move ToDos to features/, add status update and Daly BMS
    - README: status paragraph updated (Sept '26, by Etienne)
    - README: "Done ToDo's" removed, "ToDo" replaced by a pointer to
    features/INDEX.md (open ToDos already tracked as WINCH-12/13/14)
    - parts-list: Daly BMS R24TS (7-17S, 300A, active balancing), added Aug '26
2026-09-28 parts-list: Mark 16S balancer board as replaced by Daly BMS
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2026-09-30 WINCH-18: Document potentiometer wiring and part spec (ADC2)
    - vesc/readme.md: potentiometer wiring (GND / ADC2 / VCC, as described
    by Etienne), check after wiring, part recommendation (10k linear),
    failure modes; emphasise "ADC2 to GND without potentiometer".
    - New feature WINCH-18 (safety-relevant), cross-reference in WINCH-08.
    - features/INDEX.md: fix broken table (blank line before WINCH-16),
    add WINCH-18.
2026-09-30 WINCH-05/06/07, WINCH-19/20/21: Drop line cutter, auto fan, pinned libs, usage docs
    Firmware (safety-relevant, flash TX + RX together):
    - WINCH-05: remove 3rd button, servo / line cutter and the servo field.
    - WINCH-07: receiver switches the cooling fan by itself (on while
    state >= 1 incl. failsafe, off 120 s after the last pull state);
    relay polarity via RELAY_ACTIVE_HIGH; relay field removed.
    - LoraTxMessage is now 3 bytes (was 5); static_asserts check 3/4 bytes
    in both sketches. Admin (ID 0) startup scan now requires the exact
    packet size, so the 4-byte ack can't be read as a TX message.
    - Both sketches compile (arduino-cli, esp32 core 2.0.15); not flashed,
    not bench-tested.
    Do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
    [Button2Test.ino, ButtonLoop.ino, CustomButtonStateHandler.ino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]
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2026-09-30 WINCH-17: Hall mode + KTY83 temp sensor on the VESC, archive old configs
    VESC Tool 3.01 session with Etienne (FW 5.3 confirmed):
    - Red LED with the sensor cable connected was FAULT_CODE_OVER_TEMP_MOTOR:
    temp sensor type was NTC 10k, the motor has a KTY83-122 (~100 C read).
    Set to KTY83/122.
    - Hall detection (hall table 255,65,118,103,199,34,173,255), FOC sensor
    mode Hall. Potentiometer test: smooth start and braking at low speed.
    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
    [240601_app_config.xml, 240601_motor_config.xml, 260930_app_config.xml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]
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2026-10-02 WINCH-05/16: Pre-flash firmware backup and wiring check
    WINCH-05: "Before flashing" section with esptool backup/restore of both
    boards and a wiring check with the old firmware (relay, UART).
    WINCH-16: Board pinout shows LoRa reset on GPIO23, code uses RST 14
    (= UART RX); suspect for frozen telemetry. No microSD card in receiver.
2026-10-03 WINCH-07/15/16: Relay wiring fix, LoRa RST 23, UART diagnosis, release warning
    - WINCH-07: relay signal was on GPIO15, resoldered to IO12 (relay switches,
    fan runs); boards still ran the old firmware; fan behaviour after release
    reviewed (no code change).
    - WINCH-15/16: LoRa reset pin 14 -> 23 in both sketches (IO14 is also
    VESC_RX on the receiver); receiver prints UART diagnosis on the serial
    monitor; unused myMaxPull / scale copies removed from the receiver;
    failsafe comment corrected (20 s). Harness short found and repaired.
    Compiles; not bench-tested.
    - README: warning not to switch the remote off before AutoStop has stopped
    the drum; fan behaviour after release; receiver w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
    [receiver.ino, transmitter.ino]
2026-10-06 WINCH-16: UART diagnosis (VESC does not answer), receiver OLED telemetry line; WINCH-25 idea; WINCH-24 day-before list
    - Receiver OLED: new line "Tac <raw> D <duty>% ok|ERR" showing the result
    of the last UART read. Display only. Compiles; flashed by Etienne.
    - WINCH-16: debug output shows correct request frames and "Timeout";
    loopback IO2<->IO14 at the cable end passes, so ESP32 pins and cables
    are fine and the VESC COMM UART does not answer. VESC app settings
    unchanged since 2024. Debugging paused (Etienne); without telemetry the
    receiver autostop taper is inactive (VESC autostop unaffected).
    - WINCH-25 (Idea): telemetry over the VESC CAN port.
    - WINCH-07/15: bench results with t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
    [receiver.ino]
2026-10-19 WINCH-24: Add printable checklist as doc/checklist.md
    Six German checklists covering day-before, packing, setup, pulling
    out the line, the tow itself, and release/rewind. Markdown only
    (no PDF). Links from README and WINCH-09; feature file updated to
    In Progress with scope and open-questions resolved.
2026-10-19 WINCH-24: Refine checklist items 1-3 (Etienne)
    Day before: add e-bike battery charge and trailer tire pressure.
    Packing: add helmet, clarify "winch on trailer". Setup: reorder to
    match Etienne's actual sequence (cover off, uncouple trailer and
    deploy legs, precharge battery via antispark plugs, unpack alu box,
    fix winch, antenna, camera, full battery connect, then controller).
